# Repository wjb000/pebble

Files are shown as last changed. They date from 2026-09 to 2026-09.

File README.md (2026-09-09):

# Pebble — HouseHand v3

Draft wheeled house-chore bot. App pages:

- **Model:** [/pebble/model](https://wjb000.github.io/pebble/model)
- **Sim:** [/pebble/sim](https://wjb000.github.io/pebble/sim) — teleop, chore demo, **Train BC / Test AI**
- **BOM:** [/pebble/bom](https://wjb000.github.io/pebble/bom)
- **Docs:** [/pebble/docs](https://wjb000.github.io/pebble/docs) — print kit + assembly + AI

Twin: LeKiwi 3-wheel omni → torso → XLe shoulder deck → dual SO-101 + cam head.  
Print: `print/README.md` · Assembly: `docs/ASSEMBLY.md` · Train: `docs/TRAIN.md`

## Controls (sim)

W/S forward · A/D strafe · ←/→ yaw · Q/E arms · F pick · G demo · TAB mode · Space e-stop.  
**AI:** teleop to record → Train BC → Test AI (panel on `/sim`).

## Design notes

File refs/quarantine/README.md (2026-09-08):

# Quarantine

Assets here are **not** part of the Pebble digital twin or product BOM.

- `microduck/` — leftover Pollen Microduck MJCF/NOTICE from an earlier biped experiment.
  Pebble is HouseHand v3 (omni + telescope + SO-ARM100). Do not reload into `public/assets/`.

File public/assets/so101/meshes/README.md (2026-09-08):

# SO-101 URDF visual meshes

Copied from [TheRobotStudio/SO-ARM100](https://github.com/TheRobotStudio/SO-ARM100) `Simulation/SO101/assets/` (Apache-2.0).

These are the Onshape-exported parts referenced by `../so101_new_calib.urdf` (meters). Print the follower from `print/SO101/Individual/` instead of these sim meshes.

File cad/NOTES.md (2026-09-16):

# CAD notes

HouseHand printable structure is generated from one geometry contract:

| Constant | Value | Role |
|---|---:|---|
| `TORSO_OD` / wall | 180 / **6 mm** | Clears 4″ omni tops; thicker wall for dual-arm load |
| `TORSO_FLANGE_OD` | 190 mm | Bolts to layer2; **wheel wells** over forward omnis |
| Flange bolts | `(40,±80)`, `(±80,±40)` | **6× Ø3.4** — `(−40,±80)` sit in the wells |
| Wheel wells | print 90–144° / 214–271°, Z=0–36 | Forward 4″ omnis spin through flange + lower tube |
| Split ring | Z=155–165, r=88, 6× M3 | Bed-size halves clamp (plus 4 pins) |
| Deck → torso | r=88, 30°/90°/… | **6× M3** through plate into top rim |
| Pad centers | (−26, ±138) mm | SO-101 L/R; **4× Ø5** on SO-ARM100 4040 48×46.5 mm rectangle |
| Cable | Ø36 through deck | Into hollow torso |
| Neck boss / bolts | Ø72 / Ø36; r=28 4× M3 | Collar and **generated head** share this circle |
| Head | visor helmet, flange Ø82, 4× M3 r=28 | Forward visor + 32×32 UVC (4× M2, 28 mm) |
| Deck splice | 180×24×5, 8× M3 | L/R seam bar |

## Generate

```bash
python3 scripts/gen_structure_kit.py
python3 scripts/prep_print_stls.py   # foot origins, bed splits, registration pins
python3 scripts/verify_structure_kit.py
```

Writes identical STLs to:
- `public/assets/xlerobot/hardware/HouseHand_{torso,shoulder_deck,neck,head_mount,head_camera}.stl`
- `print/xlerobot/hardware/` (same files)
- aliases `torso_shell.stl` → torso (**do not print twice**)

OpenSCAD sources: `cad/torso_shell.scad`, `cad/shoulder_deck.scad` (reference; Python generator is authoritative).

## Twin loads

`src/components/ImportedRobots.tsx` — LeKiwi URDF + HouseHand torso/deck/neck/head + 2× SO-101 URDF.  
No `TORSO_XY_WIDEN`, no shelf-trim / Z-gap hacks. Torso sits on **layer2** top.

## Wheel / base fit

- Print kit motor mounts = URDF `drive_motor_mount-v11` (×3).
- Print kit hubs = URDF `omni_wheel_mount-v5` (×3); wheels + drive servos are bought.
- Hex standoffs between layer1 and layer2 are bought (LeKiwi BOM) — required, not printed.
- Flange OD must stay ≤190 mm. Two **wheel wells** (print ~120° / ~240°) cut the flange and the lower 36 mm of tube so the forward omnis that poke above layer2 can spin. Seat those wells over the two forward wheels (camera faces drive-forward).

## Not part of the kit

RÅSKOG cart, XLe fragments, perceptron base, Prusa Z — see `print/_archive/`.

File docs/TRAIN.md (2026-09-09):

# Train & test AI in the browser twin

The `/sim` page records teleop and trains a small **behavioral cloning** policy in-browser (no server).

## Loop

1. Open `/sim` → press **DRIVE**
2. **TAB** or Train panel → **Teleop**
3. Drive toward the beacon / box (W/A/S/D, arrows). Recording is on by default.
4. **Train BC** when you have ≥40 moving samples
5. **Test AI** — mode switches to `POLICY`; the linear net drives from the same observation vector
6. **Space** e-stop / reset pose (keeps trajectory). **Clear traj** / **Clear AI** wipe demos or weights.

## Observation → action

| Obs (normalized) | Action |
|---|---|
| ball dx/dy/bearing/range | `forward` |
| box dx/dy/range + held | `strafe` |
| v, omega, lift frac, arm shoulder | `yawRate` |

Fixed control rate **50 Hz** (`DT = 0.02`). Physics = planar holonomic mecanum (not MuJoCo).

## API

After Sim mounts:

```js
const t = window.__PEBBLE_TRAIN__
t.buffer.length
t.trainFromBuffer(40)
t.runPolicy()
t.downloadTrajectory()
t.downloadPolicy()
```

Weights persist in `localStorage` (`pebble-bc-policy-v1`).

## Honest limits

- BC copies your teleop style — garbage demos → garbage policy
- No vision / depth — state features only
- Arms/lift are observed but the action is base steering only (extend later)
- Stub **AUTO** (TAB) is still the simple beacon seeker when no policy is running

Print kit: `print/README.md`. Assembly: `docs/ASSEMBLY.md`.

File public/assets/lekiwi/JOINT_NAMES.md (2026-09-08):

# URDF joint names

The nine actuated joints use the same names as the LeKiwi motors in
[LeRobot](https://github.com/huggingface/lerobot/blob/main/src/lerobot/robots/lekiwi/lekiwi.py).
This makes joint-state and command dictionaries directly comparable between the
robot driver and the URDF.

| LeRobot/URDF name | Previous generated URDF name |
| --- | --- |
| `base_left_wheel` | `ST3215_Servo_Motor-v1_Revolute-64` |
| `base_back_wheel` | `ST3215_Servo_Motor-v1-2_Revolute-60` |
| `base_right_wheel` | `ST3215_Servo_Motor-v1-1_Revolute-62` |
| `arm_shoulder_pan` | `STS3215_03a-v1_Revolute-45` |
| `arm_shoulder_lift` | `STS3215_03a-v1-1_Revolute-49` |
| `arm_elbow_flex` | `STS3215_03a-v1-2_Revolute-51` |
| `arm_wrist_flex` | `STS3215_03a-v1-3_Revolute-53` |
| `arm_wrist_roll` | `STS3215_03a_Wrist_Roll-v1_Revolute-55` |
| `arm_gripper` | `STS3215_03a-v1-4_Revolute-57` |

Consumers that refer to joints by name must update from the generated names in
the right column to the stable names in the left column.

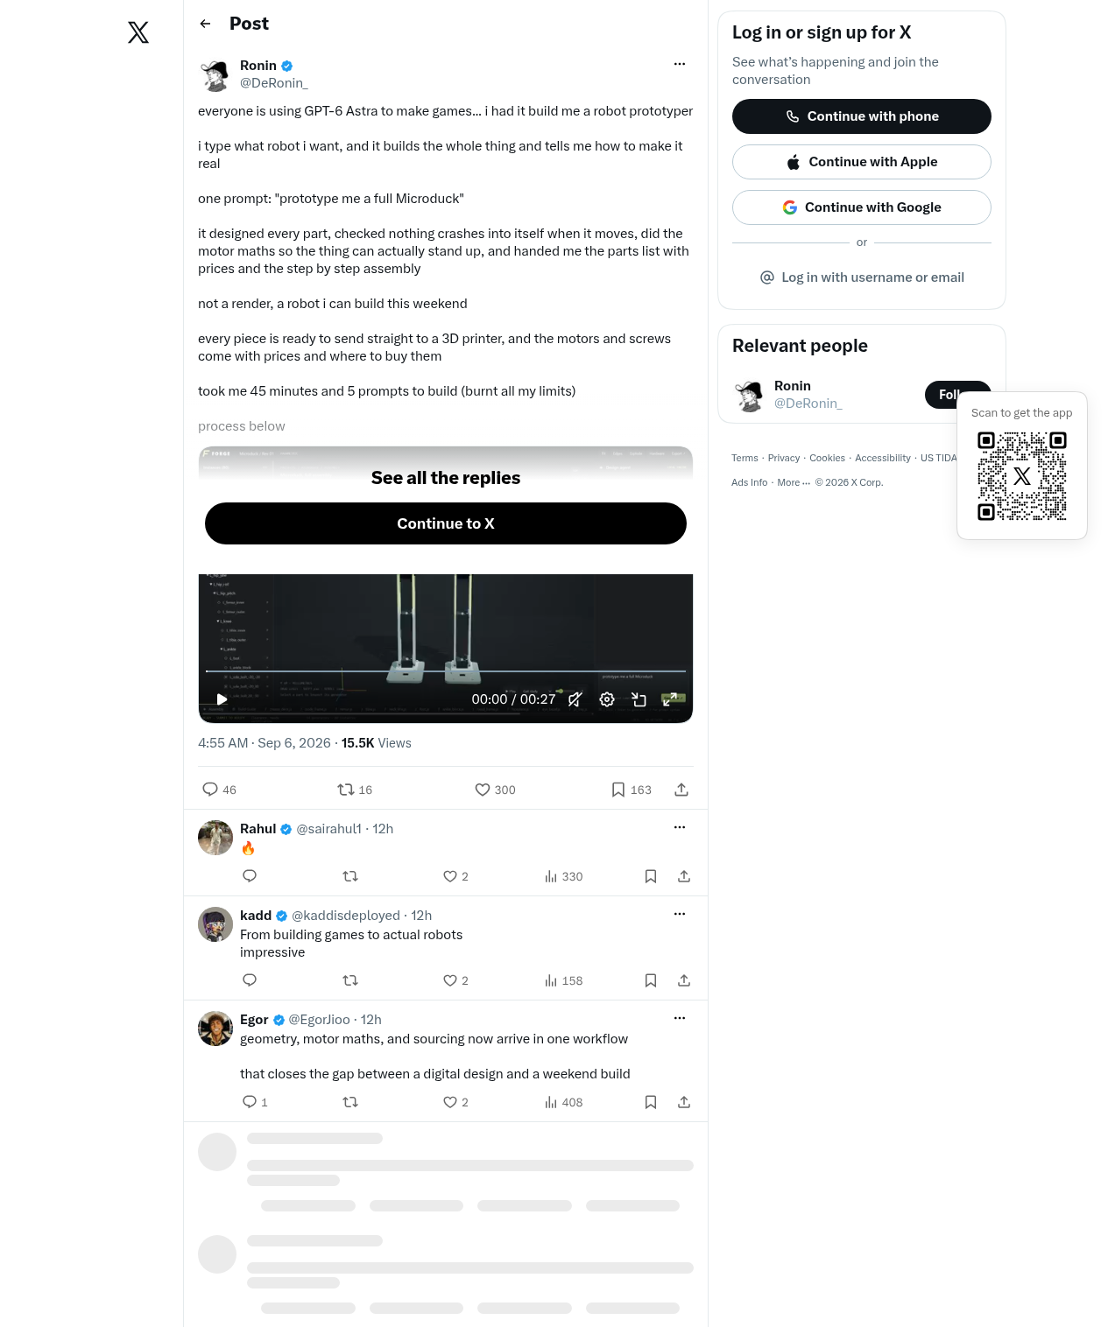
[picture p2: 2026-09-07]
refs/ronin-tweet.png

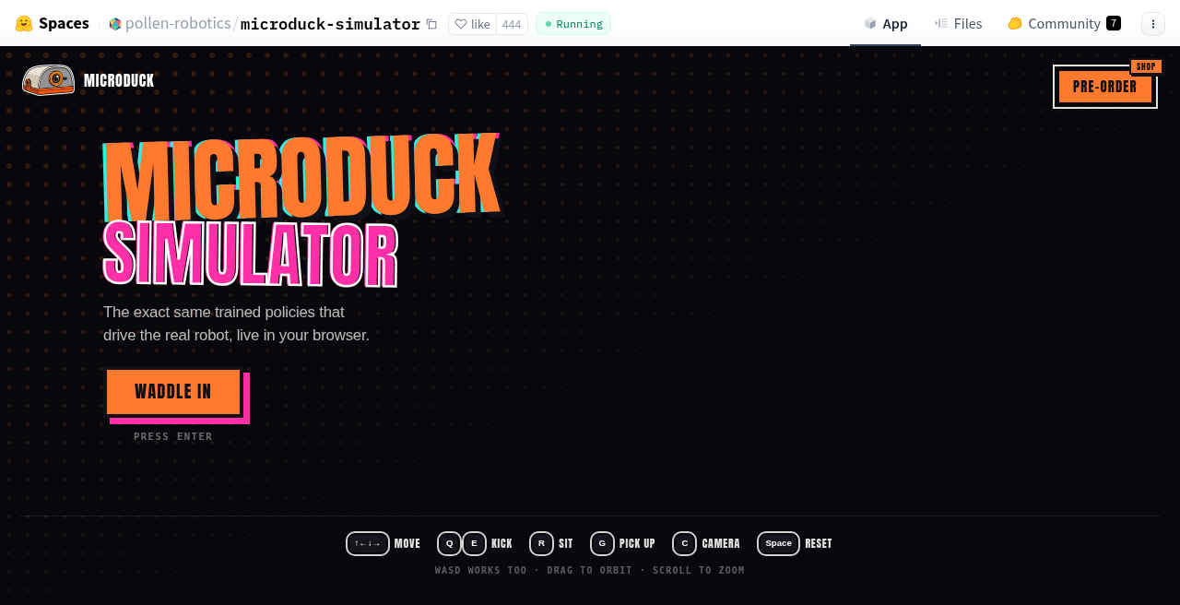
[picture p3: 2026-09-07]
refs/microduck-title.png

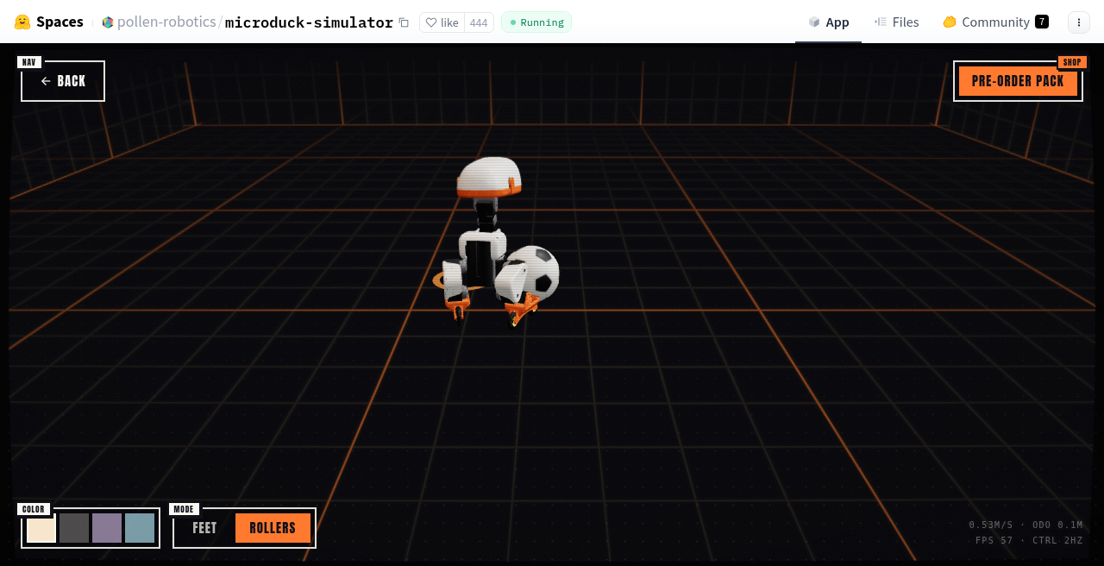
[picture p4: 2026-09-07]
refs/microduck-rollers.png

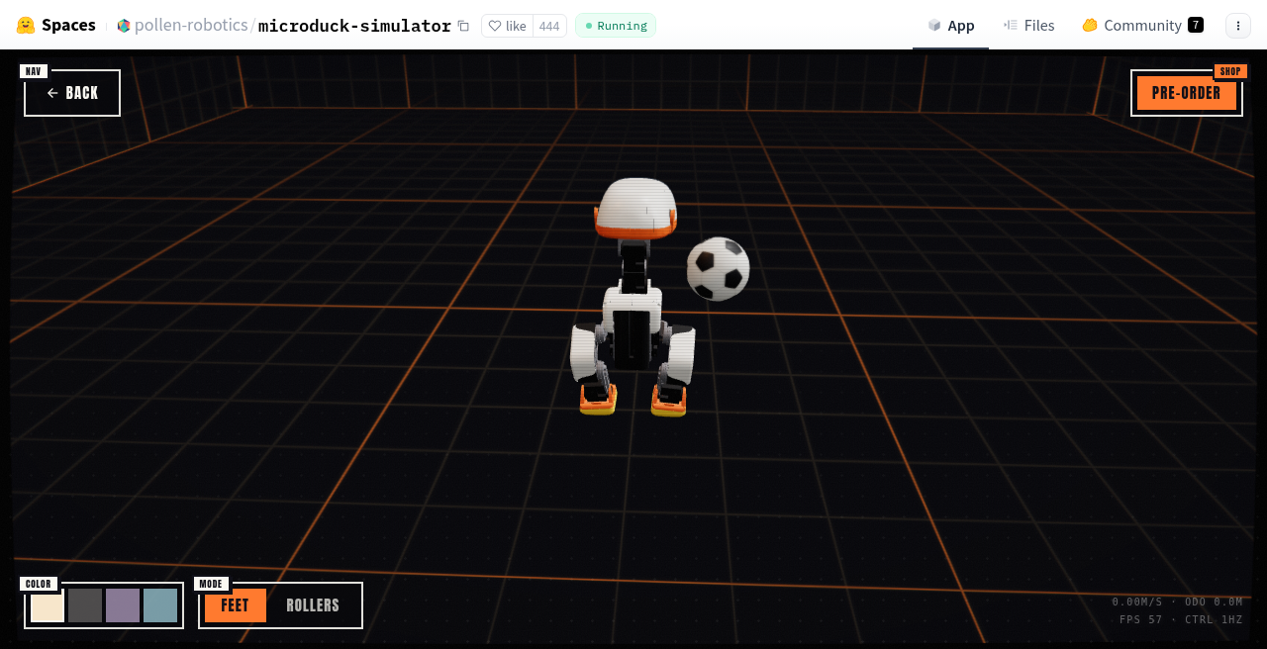
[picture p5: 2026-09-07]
refs/microduck-feet.png

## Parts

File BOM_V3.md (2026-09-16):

# HouseHand — Bill of Materials (v3.2)

**Product of record:** LeKiwi **3-omni** base + printed **HouseHand** torso/deck/neck/head + **2× SO-101** followers.  
**Rough total:** **~$500–750** DIY (print yourself). Street USD hobby prices, 2026 — verify before buy.

Print list: `print/README.md`. Assembly: `docs/ASSEMBLY.md`. Twin: `/model`.

---

## A. Arms (2× SO-101 follower)

| # | Part | Qty | ~$ | Notes |
|---|---|---:|---:|---|
| A1 | Feetech STS3215 (C001 / 7.4V or 12V match) | **12** | 168 | 6 per follower |
| A2 | Waveshare bus servo adapter | 2 | 22 | One bus per arm |
| A3 | 5V ≥5A (or 12V) rail for arms | 1–2 | 12–24 | Match motor voltage |
| A4 | USB-C data cables | 2 | 8 | Bus → host |
| A5 | PLA+/PETG filament (2× follower) | ~0.8 kg | 16 | `print/SO101/` |
| A6 | Wrist UVC cams (optional) | 0–2 | 0–30 | + `Wrist_camera_mount_SO101.stl` ×2 |
| | **Arms subtotal** | | **~$230–270** | |

Upstream: https://github.com/TheRobotStudio/SO-ARM100

---

## B. HouseHand structure (printed)

| # | Part | Qty | ~$ | Notes |
|---|---|---:|---:|---|
| B1 | `HouseHand_torso.stl` Ø180 / **6 mm wall** / flange Ø190 × 320 mm | 1 | filament | Seats on layer2; **wheel wells** over forward omnis; split ring if bed-limited |
| B2 | `HouseHand_shoulder_deck.stl` (+ splice if L/R) | 1 | filament | Pads (−26, ±138); Ø36 cable hole |
| B3 | `HouseHand_neck.stl` | 1 | filament | 4× M3 into deck boss |
| B4 | `HouseHand_head_mount.stl` visor helmet + `HouseHand_head_camera.stl` | 1 | filament | Head flange **prints** 4× M3 at r=28; visor takes 32×32 UVC + clamp plate |
| B5 | M3 + M4 hardware pack | 1 | 12–18 | Flange **6×M3**, rim 6×M3, split 6×M3, splice 8×M3, neck/head 8×M3, pads **8× M4×30** + wing nuts |
| | **Structure subtotal** | | **~$25–45** | filament + fasteners |

Generate: `python3 scripts/gen_structure_kit.py`

---

## C. LeKiwi omni base

| # | Part | Qty | ~$ | Notes |
|---|---|---:|---:|---|
| C1 | Printed plates + mounts (`print/lekiwi/`) | 1 set | filament | layer1, layer2, 3× drive mount v11, 3× hub, battery, Pi case, controller mount |
| C2 | **4″ omni wheels** (bought) | **3** | 35–50 | Not printed |
| C3 | **STS3215 drive servos** | **3** | 42–50 | Bridge: mount → hub → wheel |
| C4 | Waveshare bus (drive) | 1 | 11 | Or share a bus carefully |
| C5 | **Hex standoffs** McMaster-class **`94868A713`** (M3 ♀ threaded, ~50 mm stack height per URDF) | **6** | 8–15 | **Required** between layer1 ↔ layer2 |
| C6 | M3 screws for plates / mounts / standoffs | — | 8–12 | |
| | **Base subtotal** | | **~$110–160** | |

Upstream: https://github.com/SIGRobotics-UIUC/LeKiwi

---

## D. Power, compute, safety

| # | Part | Qty | ~$ | Notes |
|---|---|---:|---:|---|
| D1 | 12 V pack + BMS (centered in base bay) | 1 | 50–120 | Tip ballast |
| D2 | 5 V buck | 1–2 | 5–10 | Logic / hub / cams |
| D3 | Powered USB hub | 1 | 15 | Buses + cams |
| D4 | Laptop you own **or** Pi 5 | 0–1 | 0–80 | |
| D5 | USB gamepad | 1 | 20 | Teleop |
| D6 | Latching e-stop | 1 | 8–12 | Cuts drive + arms |
| D7 | Wire, XT60, fuses, switch | — | 15–25 | |
| D8 | Head UVC camera | 1 | 15–30 | On HouseHand head mount |
| | **Power/compute subtotal** | | **~$130–280** | |

---

## Cost rollup

| Block | Low | High |
|---|---:|---:|
| A Arms | 230 | 270 |
| B Structure (print) | 25 | 45 |
| C Omni base | 110 | 160 |
| D Power/compute | 130 | 220 |
| **Total** | **~$495** | **~$695** |

---

## Buy order
1. **C2+C3+C5** — omni wheels, 3× drive STS3215, **6× standoffs** (base cannot assemble without these)
2. **A1** — first 6× STS + one follower bring-up
3. Rest of **A** — second arm
4. Print **C1 + B** while hardware ships
5. **D** — pack, e-stop, compute, head cam

## Do not buy
RÅSKOG cart · 4× mecanum deck (this twin is **3-omni**) · ODrive/SteadyWin · Amazing Hand · nested telescoping column kit · exposed-rail-only lift · leader SO-101 (unless you want teleop leader)

## Sketch
- Twin stack on `/model` matches `print/` STLs
- This BOM: `BOM_V3.md` · UI: `/bom`

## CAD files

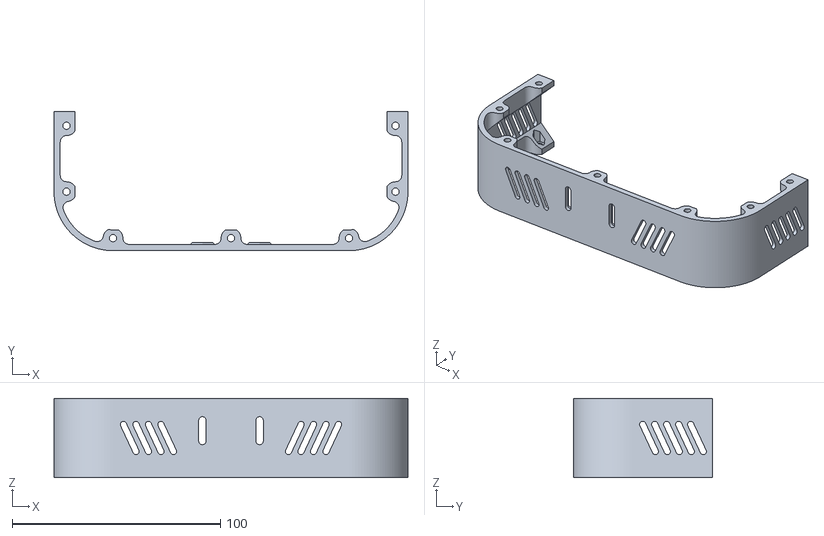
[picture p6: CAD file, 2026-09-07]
print/base/back_lower_wall.stl
170.0 x 66.9 x 38.0

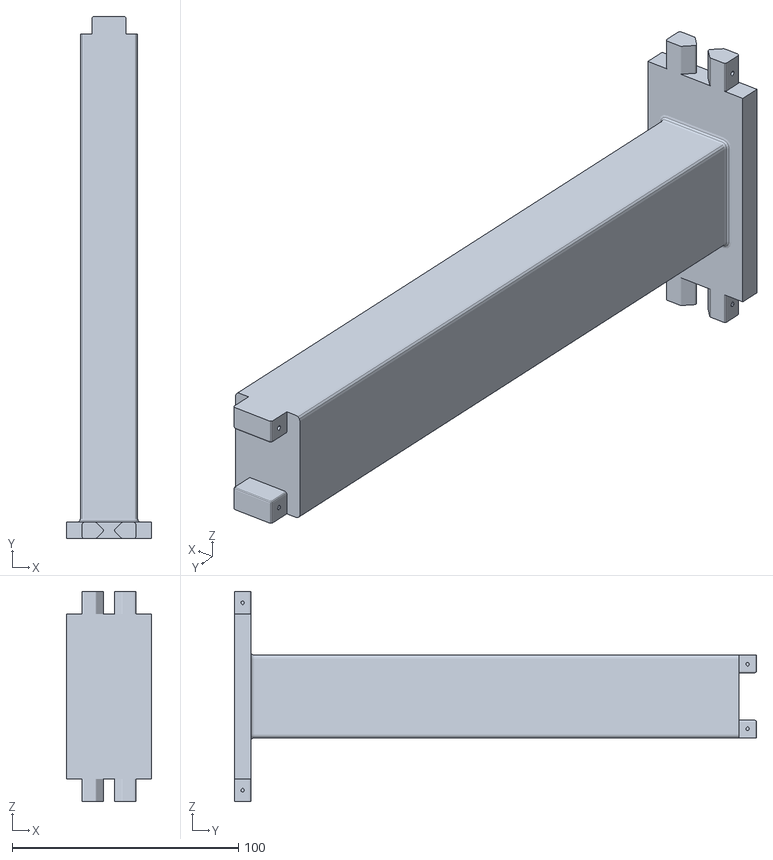
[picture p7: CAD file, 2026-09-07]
print/head/cam_mount_bottom.stl
37.4 x 230.9 x 93.0

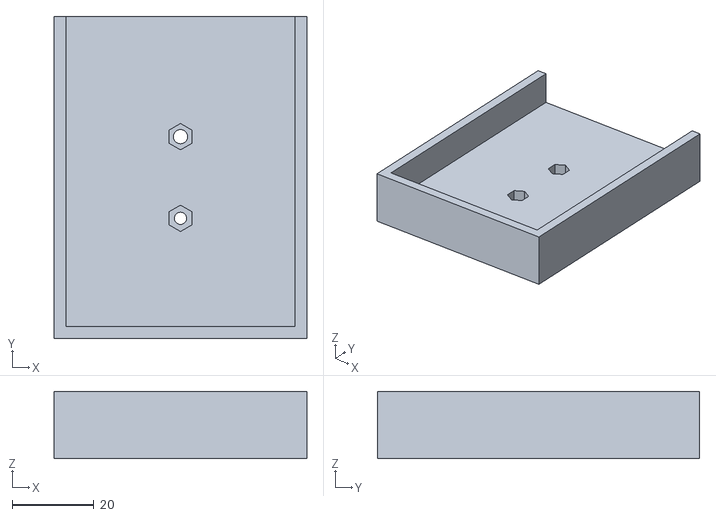
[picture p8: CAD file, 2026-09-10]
print/lekiwi/battery_mount.stl
62.0 x 79.0 x 16.5

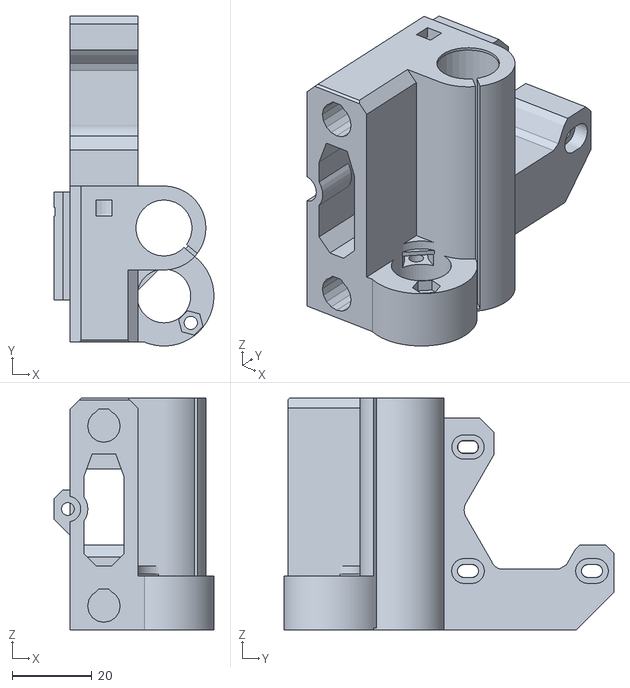
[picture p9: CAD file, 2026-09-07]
print/lift/carriage_x-end-motor.stl
40.0 x 82.5 x 58.0

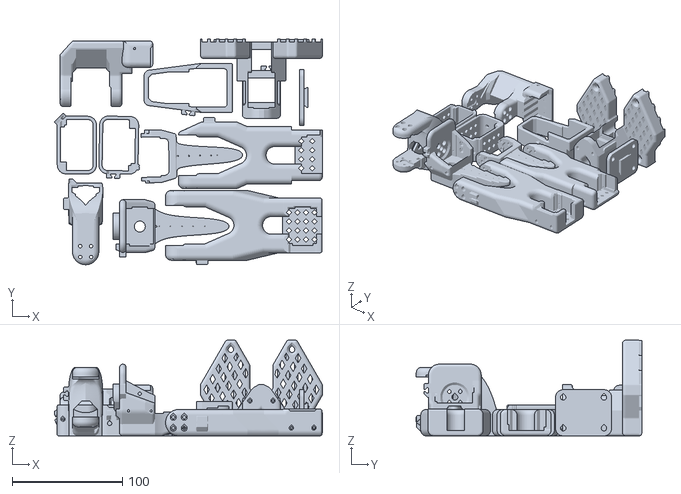
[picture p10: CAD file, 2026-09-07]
print/SO101/Follower/Prusa_Follower_SO101.stl
243.4 x 204.9 x 87.0

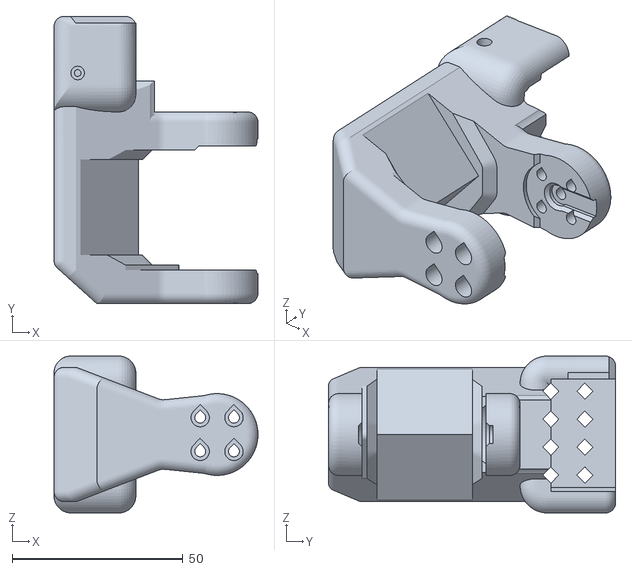
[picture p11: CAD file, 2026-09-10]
print/SO101/Individual/Rotation_Pitch_SO101.stl
59.8 x 84.2 x 46.0

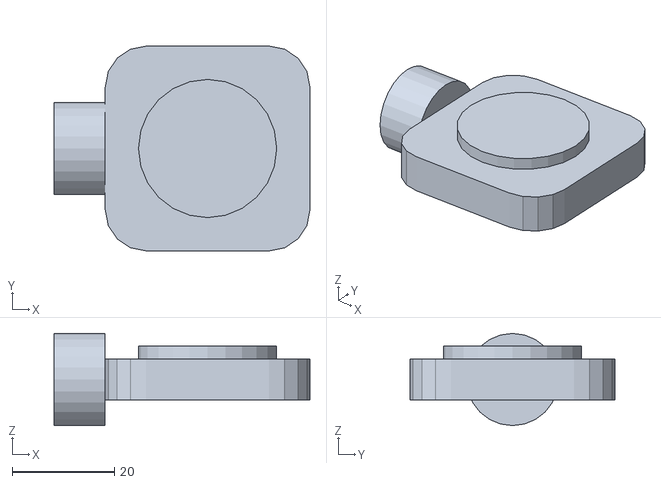
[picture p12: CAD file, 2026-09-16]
print/xlerobot/hardware/HouseHand_head_camera.stl
50.0 x 40.0 x 18.0

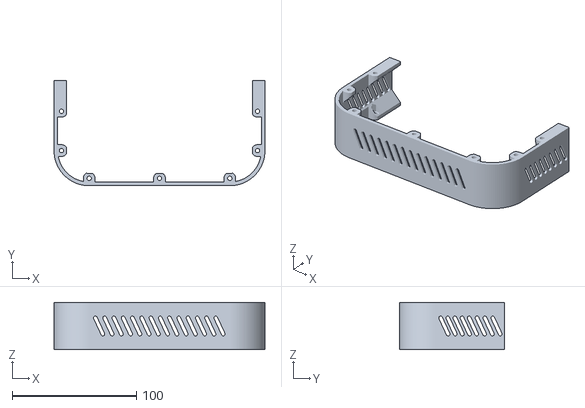
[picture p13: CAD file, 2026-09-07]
public/assets/base/back_upper_wall.stl
170.0 x 85.0 x 38.0

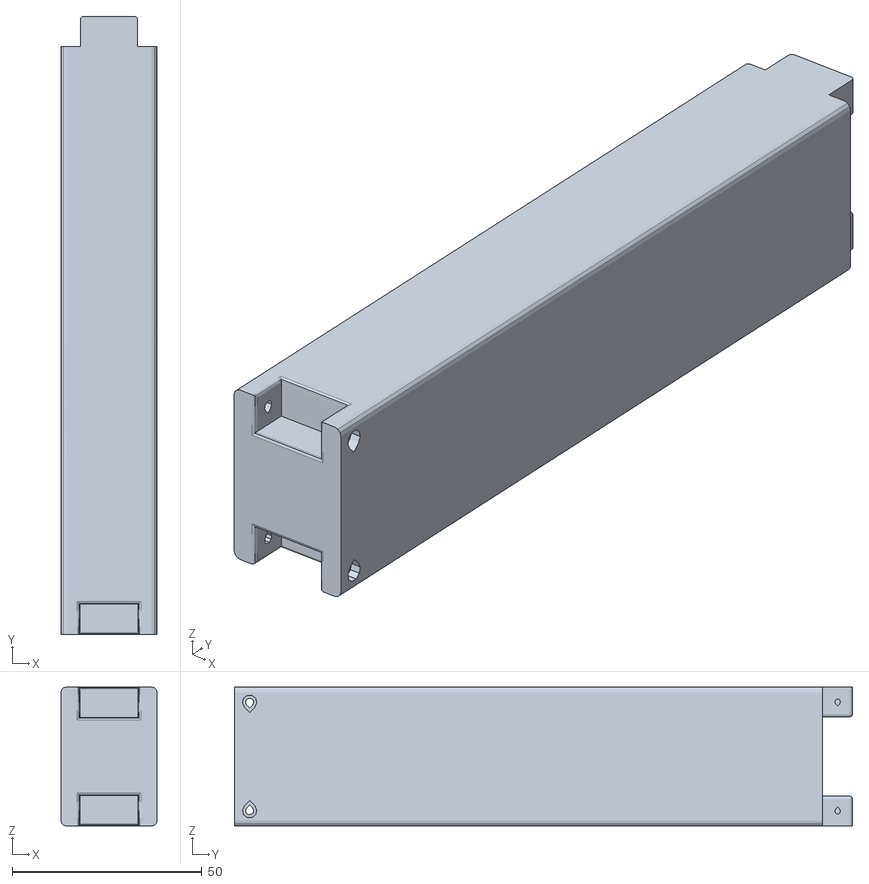
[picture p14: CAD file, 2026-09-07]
public/assets/head/cam_mount_middle.stl
25.4 x 162.9 x 36.6

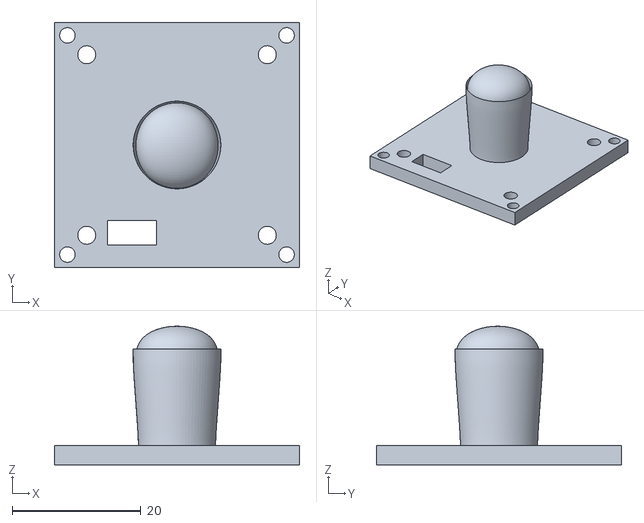
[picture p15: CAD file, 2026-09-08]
public/assets/lekiwi/meshes/Camera-Model-v3.stl
38.0 x 38.0 x 21.5

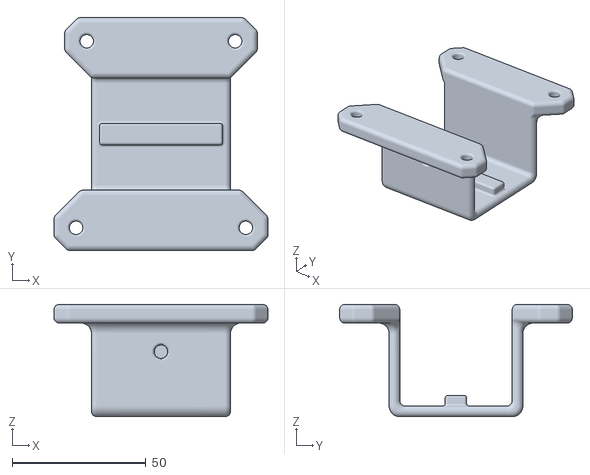
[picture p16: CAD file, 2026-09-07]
public/assets/lift/4040_base_mount.stl
80.0 x 87.0 x 42.0

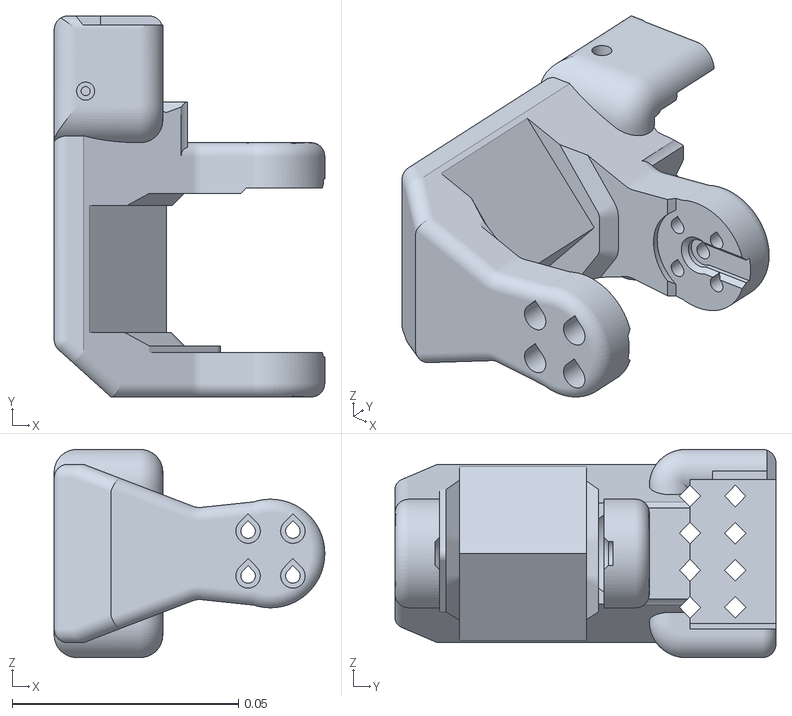
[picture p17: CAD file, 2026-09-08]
public/assets/so101/meshes/rotation_pitch_so101_v1.stl
0.0598 x 0.0842 x 0.046

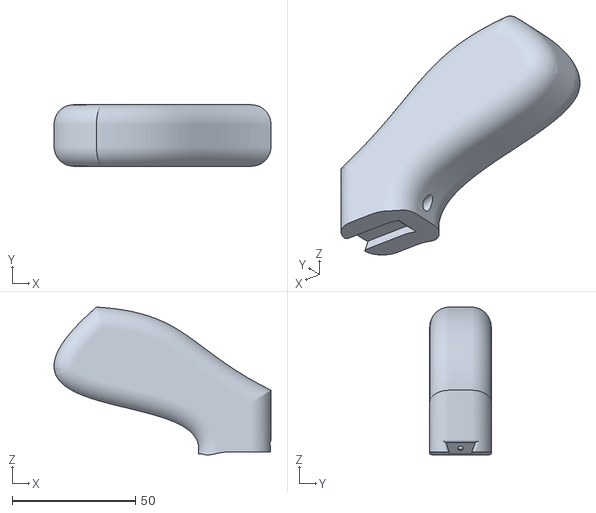
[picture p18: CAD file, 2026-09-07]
public/assets/so101/print/Handle_SO101.stl
88.1 x 25.0 x 60.1

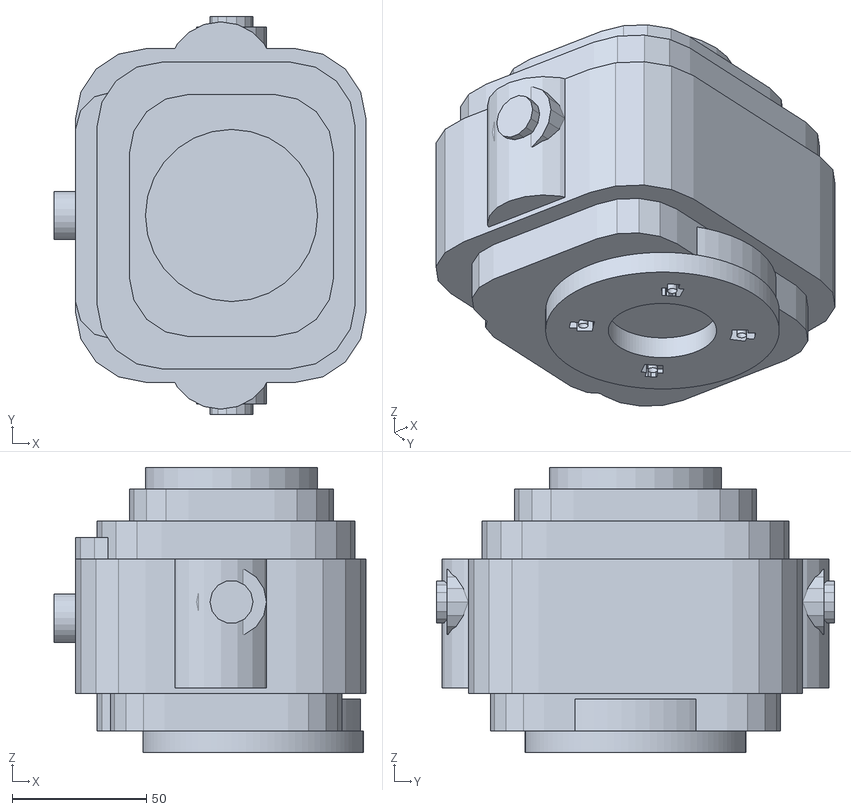
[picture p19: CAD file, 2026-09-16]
public/assets/xlerobot/hardware/HouseHand_head_mount.stl
116.0 x 148.0 x 106.0

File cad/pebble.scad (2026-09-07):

// Pebble CAD twin — chore-class body + 2× SO-101 arms
// MUST MATCH src/robot/dims.ts (hardcoded constants below).
// Units: millimeters. Open in OpenSCAD: File → Open → F5 preview / F6 render.
// NOT an official Pollen / legacy-ref product — public specs only.

// ===== must match dims.ts =====
XL330_L = 20.0;
XL330_W = 34.0;
XL330_H = 26.0;

STS3215_L = 45.2;
STS3215_W = 24.7;
STS3215_H = 35.0;

FOOT_L = 55;
FOOT_W = 32;
FOOT_H = 12;

SHIN_LEN = 48;
THIGH_LEN = 42;

PELVIS_W = 72;
PELVIS_H = 20;
PELVIS_D = 48;

TORSO_W = 100;
TORSO_H = 68;
TORSO_D = 78;

NECK_LEN = 22;

HEAD_W = 48;
HEAD_H = 38;
HEAD_D = 52;

BEAK_L = 28;
BEAK_W = 16;
BEAK_H = 10;

CAMERA_W = 12;
CAMERA_H = 12;
CAMERA_D = 8;

LINK_R = 6;
HORN_THICKNESS = 2.5;

SO101_UPPER = 112.6;
SO101_FORE = 134.9;
SO101_WRIST = 61.1;
SO101_GRIP = 80;
SO101_BASE_Z = 62.4;

SHOULDER_SPAN = 140;
HIP_LATERAL = 30;

PI_W = 65;
PI_H = 30;
PI_D = 12;

BAT_W = 40;
BAT_H = 18;
BAT_D = 30;

JOINT_YAW_TO_ROLL = 12;
JOINT_ROLL_TO_PITCH = 16;

STANDING_HEIGHT =
  FOOT_H + SHIN_LEN + THIGH_LEN + PELVIS_H + TORSO_H + NECK_LEN + HEAD_H;
// expect 250
HIP_HEIGHT = FOOT_H + SHIN_LEN + THIGH_LEN; // 102

$fn = 24;

module servo_xl330() {
  color([0.2, 0.22, 0.26])
    cube([XL330_L, XL330_H, XL330_W], center = true);
  color([0.95, 0.45, 0.1])
    translate([XL330_L * 0.35, 0, 0])
      rotate([0, 90, 0])
        cylinder(h = HORN_THICKNESS, r = 2.5, center = true);
}

module servo_sts3215() {
  color([0.12, 0.16, 0.22])
    cube([STS3215_L, STS3215_H, STS3215_W], center = true);
  color([0.95, 0.45, 0.1])
    translate([STS3215_L * 0.35, 0, 0])
      rotate([0, 90, 0])
        cylinder(h = 3, r = 4, center = true);
}

module tube_link(len, r = LINK_R) {
  color([0.6, 0.65, 0.72])
    translate([0, -len / 2, 0])
      cylinder(h = len, r = r, center = true);
}

module foot() {
  color([0.18, 0.2, 0.24])
    translate([0, -FOOT_H / 2, FOOT_L * 0.15])
      cube([FOOT_W, FOOT_H, FOOT_L], center = true);
}

module leg(side = 1) {
  translate([side * HIP_LATERAL, 0, 0]) {
    rotate([0, 0, 90]) servo_xl330(); // hip_yaw
    translate([0, -JOINT_YAW_TO_ROLL, 0]) {
      servo_xl330(); // hip_roll
      translate([0, -JOINT_ROLL_TO_PITCH, 0]) {
        rotate([90, 0, 0]) servo_xl330(); // hip_pitch
        tube_link(THIGH_LEN, LINK_R * 0.85);
        translate([0, -THIGH_LEN, 0]) {
          rotate([90, 0, 0]) servo_xl330(); // knee
          tube_link(SHIN_LEN, LINK_R * 0.8);
          translate([0, -SHIN_LEN, 0]) {
            rotate([90, 0, 0]) servo_xl330(); // ankle
            foot();
          }
        }
      }
    }
  }
}

module duck_head() {
  rotate([90, 0, 0]) servo_xl330(); // neck_pitch
  color([0.2, 0.22, 0.26])
    translate([0, NECK_LEN * 0.4, 0])
      cylinder(h = NECK_LEN * 0.75, r1 = 10, r2 = 8, center = true);
  translate([0, NECK_LEN * 0.85, 0]) {
    rotate([90, 0, 0]) servo_xl330(); // head_pitch
    translate([0, 10, 0]) {
      rotate([0, 0, 90]) servo_xl330(); // head_yaw
      translate([0, 10, 0]) {
        servo_xl330(); // head_roll
        color([0.6, 0.64, 0.7])
          translate([0, HEAD_H * 0.25, 0])
            cube([HEAD_W, HEAD_H, HEAD_D], center = true);
        // beak
        rotate([90, 0, 0]) servo_xl330();
        color([0.95, 0.45, 0.1])
          translate([0, -2, BEAK_L * 0.45])
            cube([BEAK_W, BEAK_H, BEAK_L], center = true);
        color([0.1, 0.1, 0.12])
          translate([0, HEAD_H * 0.55 + CAMERA_H / 2, 4])
            cube([CAMERA_W, CAMERA_H, CAMERA_D], center = true);
      }
    }
  }
}

module so101_arm(side = 1) {
  translate([side * SHOULDER_SPAN / 2, TORSO_H * 0.28, 8]) {
    // mount plate
    color([0.18, 0.2, 0.24])
      translate([-side * 8, 0, 0])
        cube([18, 28, 14], center = true);
    rotate([0, 0, 90]) servo_sts3215(); // shoulder_pan
    color([0.2, 0.22, 0.26])
      translate([0, SO101_BASE_Z * 0.35, 0])
        cylinder(h = SO101_BASE_Z * 0.7, r1 = 20, r2 = 18, center = true);
    translate([0, SO101_BASE_Z * 0.75, 0]) {
      servo_sts3215(); // shoulder_lift
      rotate([30, 0, side * 5]) {
        tube_link(SO101_UPPER, 10);
        translate([0, -SO101_UPPER, 0]) {
          rotate([90, 0, 0]) servo_sts3215(); // elbow
          rotate([-65, 0, 0]) {
            tube_link(SO101_FORE, 9);
            translate([0, -SO101_FORE, 0]) {
              rotate([90, 0, 0]) servo_sts3215(); // wrist_flex
              translate([0, -SO101_WRIST * 0.35, 0]) {
                servo_sts3215(); // wrist_roll
                translate([0, -SO101_WRIST * 0.7, 0]) {
                  rotate([0, 0, 90]) servo_sts3215(); // gripper
                  color([0.8, 0.82, 0.86]) {
                    translate([-12, -SO101_GRIP * 0.35, 0])
                      cube([8, SO101_GRIP * 0.7, 14], center = true);
                    translate([12, -SO101_GRIP * 0.35, 0])
                      cube([8, SO101_GRIP * 0.7, 14], center = true);
                  }
                }
              }
            }
          }
        }
      }
    }
  }
}

module pebble() {
  translate([0, HIP_HEIGHT, 0]) {
    color([0.18, 0.2, 0.24])
      cube([PELVIS_W, PELVIS_H, PELVIS_D], center = true);
    leg(+1);
    leg(-1);
    translate([0, PELVIS_H / 2 + TORSO_H / 2, 0]) {
      color([0.6, 0.64, 0.7])
        cube([TORSO_W, TORSO_H, TORSO_D], center = true);
      color([0.15, 0.45, 0.3])
        translate([-12, 8, -TORSO_D * 0.28])
          cube([PI_W, PI_H, PI_D], center = true);
      color([0.2, 0.22, 0.26])
        translate([22, -12, -TORSO_D * 0.28])
          cube([BAT_W, BAT_H, BAT_D], center = true);
      translate([0, TORSO_H / 2 + NECK_LEN * 0.1, 0])
        duck_head();
      so101_arm(+1);
      so101_arm(-1);
    }
  }
  color([0.95, 0.45, 0.1]) {
    translate([120, STANDING_HEIGHT / 2, 0])
      cube([3, STANDING_HEIGHT, 3], center = true);
    translate([120, 0, 0]) cube([24, 2, 24], center = true);
    translate([120, STANDING_HEIGHT, 0]) cube([24, 2, 24], center = true);
  }
}

echo(str("STANDING_HEIGHT_MM = ", STANDING_HEIGHT, " (must be 250)"));
echo(str("HIP_HEIGHT_MM = ", HIP_HEIGHT));
echo("must match dims.ts — legacy-ref body + SO-101 arms");

pebble();

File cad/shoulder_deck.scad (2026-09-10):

// HouseHand shoulder deck — dual SO-101 pads + neck boss.
// Units: mm. Flat on bed. Prefer: python3 scripts/gen_structure_kit.py

plate_x = 200;
plate_y = 380;
plate_z = 12;
corner_r = 28;

pad_x = -26;
pad_half_y = 138;
pad_r = 52;
pad_z = 6;
// 4× Ø5 on SO-ARM100 4040 pattern (see scripts/gen_structure_kit.py)

torso_od = 180;
ring_clear = 0.6;
ring_z = 4;

neck_boss_r = 36;
neck_boss_z = 14;
neck_hole_r = 18;

module rounded_plate(wx, wy, hz, r) {
  hull() for (sx = [-1, 1], sy = [-1, 1])
    translate([sx * (wx/2 - r), sy * (wy/2 - r), 0])
      cylinder(h = hz, r = r, $fn = 48);
}

difference() {
  union() {
    rounded_plate(plate_x, plate_y, plate_z, corner_r);
    // registration ring (underside)
    translate([0, 0, -ring_z])
      difference() {
        cylinder(h = ring_z, r = torso_od/2 + ring_clear + 3, $fn = 96);
        translate([0, 0, -0.1])
          cylinder(h = ring_z + 0.2, r = torso_od/2 + ring_clear, $fn = 96);
      }
    // SO-101 pads
    for (sy = [-1, 1]) {
      translate([pad_x, sy * pad_half_y, plate_z])
        cylinder(h = pad_z, r = pad_r, $fn = 64);
    }
    // neck boss
    translate([0, 0, plate_z])
      difference() {
        cylinder(h = neck_boss_z, r = neck_boss_r, $fn = 64);
        translate([0, 0, -0.1])
          cylinder(h = neck_boss_z + 0.2, r = neck_hole_r, $fn = 48);
      }
  }
}

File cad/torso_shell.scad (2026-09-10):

// HouseHand torso — mates LeKiwi layer2 (bottom) + shoulder deck (top).
// Units: mm. Export STL → print/xlerobot/hardware/HouseHand_torso.stl
// Prefer: python3 scripts/gen_structure_kit.py  (same geometry — authoritative)
//
// Two forward 4″ omnis poke above layer2. Wheel wells (print 90–144° /
// 214–271°) cut the flange + lower 36 mm of tube so the tires can spin.
// Seat those wells over the forward omnis (camera faces drive-forward).
// Flange bolts: 6× M3 on the layer2 20 mm grid. (−40, ±80) sit in the wells.

OD = 180;
WALL = 6;
H = 320;
FLANGE_OD = 190;
FLANGE_Z = 10;
RIM_Z = 6;
WHEEL_WELL_Z = 36;
HOLE_R = 1.7; // M3 clearance
BOLTS = [
  [40, 80], [40, -80],
  [80, 40], [80, -40], [-80, 40], [-80, -40]
];
WELLS = [[90, 144], [214, 271]];
$fn = 72;

module well_cut(a0, a1, h) {
  rotate([0, 0, a0])
    rotate_extrude(angle = a1 - a0)
      square([FLANGE_OD / 2 + 2, h]);
}

difference() {
  union() {
    cylinder(h = FLANGE_Z, d = FLANGE_OD);
    translate([0, 0, FLANGE_Z])
      cylinder(h = H - FLANGE_Z - RIM_Z, d = OD);
    translate([0, 0, H - RIM_Z])
      cylinder(h = RIM_Z, d = OD + 4);
  }
  translate([0, 0, -1])
    cylinder(h = H + 2, d = OD - 2 * WALL);
  for (b = BOLTS)
    translate([b[0], b[1], -1])
      cylinder(h = FLANGE_Z + 2, r = HOLE_R, $fn = 24);
  for (w = WELLS)
    translate([0, 0, -1])
      well_cut(w[0], w[1], WHEEL_WELL_Z + 2);
}

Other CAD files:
public/assets/xlerobot/xlerobot/meshes/xlerobot/assets/Lower_Arm_Motor.stl
print/base/wheel_frame.stl
print/lekiwi/base_plate_layer2.stl
print/SO101/Individual/Base_SO101.stl
print/SO101/Individual/Base_motor_holder_SO101.stl
print/SO101/Individual/Motor_holder_SO101_Base.stl
print/SO101/Individual/Motor_holder_SO101_Wrist.stl
print/SO101/Individual/Moving_Jaw_SO101.stl
print/SO101/Individual/Under_arm_SO101.stl
print/SO101/Individual/Upper_arm_SO101.stl
print/SO101/Individual/Wrist_Roll_Follower_SO101.stl
print/SO101/Individual/Wrist_Roll_Pitch_SO101.stl
print/SO101/Individual/Wrist_camera_mount_SO101.stl
print/_archive/SO101/leader/Trigger_SO101.stl
print/_archive/SO101/leader/Wrist_Roll_SO101.stl
print/_archive/base/front_lower_wall.stl
print/_archive/base/front_upper_wall.stl
print/_archive/base/lower_plate.stl
print/_archive/base/middle_plate_raspberry.stl
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

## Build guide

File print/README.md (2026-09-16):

# HouseHand / Pebble — print kit (one robot)

Send **only** these folders to the slicer. The twin on `/model` loads the **same** STLs.

**Stack:** LeKiwi 3-omni base → **HouseHand torso Ø180 / flange Ø190** → **shoulder deck** → **2× SO-101** → **neck** → **head + cam**

Do **not** print `print/_archive/` (legacy, leader-only, optional extras).

---

## Bed size (read this first)

| Part | Full size | Fits typical bed? | Split STLs (≤220 mm) |
|---|---|---|---|
| Torso | **190×190×320** | Needs **Z ≥ 320** | `HouseHand_torso_bottom.stl` + `_top.stl` (split bolt-ring + **4 registration pins**) — **6× M3×16** at seam |
| Shoulder deck | **200×380×30** | Needs **one axis ≥ 380** | `_L` + `_R` + `HouseHand_deck_splice.stl` (**8× M3**) — pins on cut |
| SO-101 Prusa plate | **~243×205×87** | Needs **≥250 mm** bed | Else print `SO101/Individual/` ×2 |
| Everything else | ≤200 mm | Fine on 220³ | — |

All kit STLs under `print/` are **footed to bed origin** (min-Z = 0). Hardware XY is centered; LeKiwi / SO-101 keep assembly XY. Regenerate with `python3 scripts/prep_print_stls.py`.

### Torso → layer2 bolts (critical)

Flange has **6× Ø3.4 through-holes** on the LeKiwi layer2 **20 mm grid**:
`(40, ±80)` and `(±80, ±40)` mm. **Two forward-omni wells** (print ~90–144° and ~214–271°) cut the flange + lower 36 mm of tube so the 4″ wheels can spin — `(−40, ±80)` would sit in those arches and are omitted. Seat the wells over the two forward omnis (camera faces drive-forward). Use M3 through the remaining holes — not freehand drilling.

### Fastener map (printed structure)

| Joint | Hardware | Pattern |
|---|---|---|
| Torso flange → layer2 | **6× M3** | `(40,±80)`, `(±80,±40)` — wells over forward omnis |
| Torso split (if using halves) | **6× M3×16** + pins | r=88 mm, 0°/60°/… |
| Deck → torso rim | **6× M3** | r=88 mm, 30°/90°/… |
| Deck L/R splice | **8× M3** + `HouseHand_deck_splice.stl` | y=±8, x=±20/±60 |
| SO-101 pads | **4× M4 per arm** (Ø5) | 48×46.5 mm rectangle (SO-ARM100 4040 pattern) through pad+plate |
| Neck → deck boss | **4× M3** | r=28 mm @ 45° |
| Head → neck flange | **4× M3** | **printed** in `HouseHand_head_mount.stl` — same r=28 |
| Head cam module | **4× M2** | 28 mm square in the visor (32×32 UVC) + `HouseHand_head_camera.stl` clamp |
| Cable | — | Ø36 through deck + hollow torso |

---

## Master checklist

| # | Module | Path | Qty | Notes |
|---|---|---|----:|---|
| **1** | Omni base | `print/lekiwi/` | 1 set | Plates, 3× `drive_motor_mount`, 3× `servo_wheel_hub`, battery, Pi case, controller mount |
| **2** | Torso | `HouseHand_torso.stl` **or** `_bottom`+`_top` | 1 | Ø180 / **6 mm wall** / flange Ø190 → layer2, **wheel wells** over the two forward omnis. Skip `torso_shell.stl`. |
| **3** | Shoulder deck | `HouseHand_shoulder_deck.stl` **or** `_L`+`_R` + `_deck_splice` | 1 | Pads (−26, ±138); Ø36 cable hole |
| **4** | Arms | `print/SO101/` | **2×** | Follower set twice — see folder README |
| **5** | Wrist cams (opt.) | `SO101/Individual/Wrist_camera_mount_SO101.stl` | 0–2 | |
| **6** | Neck | `HouseHand_neck.stl` | 1 | Deck center boss |
| **7** | Head | `HouseHand_head_mount.stl` + `HouseHand_head_camera.stl` | 1 | Visor helmet **bolts** to neck (4× M3 at r=28). Clamp plate sandwiches a bought 32×32 UVC |

Structure files live under `print/xlerobot/hardware/`.

### Must **buy** (not printed)

| Item | Qty | Why |
|---|----:|-----|
| 4″ omni wheels | **3** | Drive |
| STS3215 drive servos | **3** | Mount → hub bridge |
| Hex standoffs M3 (`94868A713` class) | **6** | Layer1 ↔ layer2 |
| STS3215 arm servos | **12** | 2× SO-101 |
| 12 V pack, e-stop, Pi/laptop, head cam | 1 | Power / safety / compute |

Full buy list: `BOM_V3.md` · Assembly: `docs/ASSEMBLY.md`

### Regenerate structure STLs

```bash
python3 scripts/gen_structure_kit.py
python3 scripts/prep_print_stls.py   # foot origins + bed splits + registration pins
python3 scripts/verify_structure_kit.py
```

---

## Filament (rough)

| Block | PLA+/PETG |
|---|---|
| LeKiwi base | 400–600 g |
| Torso + deck + neck + head | 700–1100 g |
| 2× SO-101 follower | 600–800 g |
| **Total** | **~1.8–2.5 kg** |

Archive / optional: `print/_archive/README.md` · Sim AI: `/sim`

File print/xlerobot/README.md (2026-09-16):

# HouseHand structure printables

```bash
python3 scripts/gen_structure_kit.py
python3 scripts/prep_print_stls.py   # required: bed origin + splits
```

## Print these

| File | Qty | Size | Notes |
|---|----:|---|---|
| `hardware/HouseHand_torso.stl` | 1 | 190×190×**320** | Needs tall Z **or** use splits below |
| `hardware/HouseHand_torso_bottom.stl` | 1 | 190×190×**160** | Glue/bolt to top at mid seam |
| `hardware/HouseHand_torso_top.stl` | 1 | 184×184×**160** | |
| `hardware/HouseHand_shoulder_deck.stl` | 1 | 200×**380**×30 | Needs ≥380 mm axis **or** use L/R |
| `hardware/HouseHand_shoulder_deck_L.stl` | 1 | 200×190×30 | Bolt to R across center |
| `hardware/HouseHand_shoulder_deck_R.stl` | 1 | 200×190×30 | |
| `hardware/HouseHand_neck.stl` | 1 | 82×82×120 | 4× M3 at r=28 both ends |
| `hardware/HouseHand_head_mount.stl` | 1 | **116×148×106** | Visor helmet, neck bolt circle, 32×32 UVC visor |
| `hardware/HouseHand_head_camera.stl` | 1 | ~40×40×10 | Clamp plate sandwiches the UVC (4× M2) |

`torso_shell.stl` aliases `HouseHand_torso.stl`.

**Small beds (≤220 mm):** print `_bottom`+`_top` and `_L`+`_R` instead of the full torso/deck.

## Do not print from archive

See `print/_archive/` for old XLe decks / RÅSKOG armbase / optional overhead cam.

Base: `print/lekiwi/` · Arms: **2×** `print/SO101/` · Master: `print/README.md`

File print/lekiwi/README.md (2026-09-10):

# LeKiwi print STLs — omni base

Upstream [SIGRobotics-UIUC/LeKiwi](https://github.com/SIGRobotics-UIUC/LeKiwi) (Apache-2.0).

Print these, then buy **3× 4″ omni wheels**, **3× STS3215** drive servos, and **6× M3 hex standoffs** (`94868A713` class).  
**Do not** print the onboard LeKiwi arm — HouseHand uses **2× SO-101** on the shoulder deck.

| STL | Qty | Notes |
|-----|----:|---|
| `base_plate_layer1.stl` | 1 | Bottom plate (URDF `base_plate_layer1-v5`) |
| `base_plate_layer2.stl` | 1 | Top plate — torso bolts at `(±40,±80)` / `(±80,±40)` on the 20 mm grid |
| `drive_motor_mount.stl` | 3 | URDF `drive_motor_mount-v11` |
| `servo_wheel_hub.stl` | 3 | URDF `omni_wheel_mount-v5` — hub only; wheel bought |
| `servo_controller_mount.stl` | 1 | |
| `battery_mount.stl` (or `_eu`) | 1 | |
| `pi_case_top.stl` + `pi_case_bottom.stl` | 1 | |
| `base_camera_mount.stl` | 0–1 | Optional (head cam is on the neck) |

## Clearance / assembly

- Motors + hubs on **layer1**; hubs clear **layer2** underside ~4–5 mm.
- **6× hex standoffs** between layer1 ↔ layer2 — required, not printed.
- Drive chain: `drive_motor_mount` → **STS3215** → `servo_wheel_hub` → **4″ omni**.
- **3× omni at 120°** (LeKiwi kit layout: one aft, two forward-quarter). Do not rearrange for “symmetry” — mounts and wiring follow the kit.
- Omni tops poke above layer2; torso flange **Ø190** plus **wheel wells** over the two forward omnis so the 4″ tires can spin.
- Torso flange has **6× Ø3.4 through-holes** matching layer2’s 20 mm M3 grid (`(40,±80)`, `(±80,±40)`) — no freehand drill. `(−40,±80)` sit in the wells.
- STLs are Z-footed for the slicer (`python3 scripts/prep_print_stls.py`).
- Archived junk (wrong mounts, wrist cam, Jetson holder): `print/_archive/lekiwi/`.

Next: `HouseHand_torso.stl` → deck → **2× SO-101**. Master: `print/README.md`. Buy: `BOM_V3.md`.

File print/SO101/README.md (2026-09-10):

# SO-101 follower — print **2×**

Upstream [TheRobotStudio/SO-ARM100](https://github.com/TheRobotStudio/SO-ARM100) (Apache-2.0).

HouseHand mounts **two** followers on `HouseHand_shoulder_deck` pads (−26, ±138) mm.
Each pad has **4× Ø5** holes on the SO-ARM100 4040 pattern — bolt with **M4×30** from below and wing nuts inside the base.

## Easiest path (large bed)

Print `Follower/Prusa_Follower_SO101.stl` **twice** (one plate per arm).  
Plate is **~243×205×87 mm** — needs a **≥250 mm** bed. On ≤220 mm beds, use Individual below.

## Individual (fits ≤220 mm beds) — per arm, ×2

Follower-only parts in `Individual/` (leader parts are in `print/_archive/SO101/leader/`).  
Individual STLs are **Z-footed** for the slicer (XY kept for assembly frames).

| STL | Qty per arm |
|-----|----:|
| `Base_SO101.stl` | 1 |
| `Base_motor_holder_SO101.stl` | 1 |
| `Motor_holder_SO101_Base.stl` | 1 |
| `Under_arm_SO101.stl` | 1 |
| `Upper_arm_SO101.stl` | 1 |
| `Rotation_Pitch_SO101.stl` | 1 |
| `Wrist_Roll_Follower_SO101.stl` | 1 |
| `Wrist_Roll_Pitch_SO101.stl` | 1 |
| `Motor_holder_SO101_Wrist.stl` | 1 |
| `Moving_Jaw_SO101.stl` | 1 |
| `WaveShare_Mounting_Plate_SO101.stl` **or** `Seeedstudio_Mounting_Plate_SO101.stl` | 1 |

| Optional | Qty |
|---|----:|
| `Wrist_camera_mount_SO101.stl` | 0–1 per arm |

**Do not print** (archived leader): `Trigger_SO101`, `Handle_SO101`, `Wrist_Roll_SO101`.

## Buy

**12× STS3215** + 2× Waveshare bus. Filament ~300–400 g PLA per follower.

Master: `print/README.md` · Hardware BOM: `BOM_V3.md`

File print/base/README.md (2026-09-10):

# print/base — archived

Legacy perceptron chassis STLs have moved to `print/_archive/base/`.  
HouseHand v3 uses **LeKiwi** (`print/lekiwi/`) as the drive base.

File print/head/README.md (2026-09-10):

# print/head — alternate cam stack

SO-ARM overhead cam mounts (optional).  
**Primary** cam path (matches twin):  
`print/xlerobot/hardware/HouseHand_head_mount.stl` + `HouseHand_head_camera.stl`.

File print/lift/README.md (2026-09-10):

# print/lift — mostly archived

Prusa Z / exposed-rail STLs are in `print/_archive/lift/`.  
v3 lift is the **HouseHand torso column** (no external carriage).

Optional leftover: `4040_base_mount.stl` (only if you add 4040 bars — not in the twin).

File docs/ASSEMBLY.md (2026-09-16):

# HouseHand assembly — printable twin stack

Twin: `/model` + `/sim`. Print list: `print/README.md`. Buy list: `BOM_V3.md`.  
Generate structure: `python3 scripts/gen_structure_kit.py`.

**Product:** LeKiwi **3-omni** base + **HouseHand Ø180 torso (flange Ø190)** + shoulder deck + **2× SO-101** + neck + head cam.  
**Not** official Pollen / XLeRobot / LeKiwi. Draft — not for sale. **No RÅSKOG cart. No 4-mecanum deck.**

---

## CAD mates (locked)

1. **LeKiwi layer1** = motor deck (3× drive mount v11 + hubs + bought STS3215 + 3× 4″ omni).
2. **6× M3 hex standoffs** (`94868A713` class) space **layer1 → layer2**.
3. **HouseHand torso** Ø180 / flange Ø190 bolts to **layer2** through **6× M3** at `(40,±80)` / `(±80,±40)` (layer2 20 mm grid). **Seat the two wheel wells over the forward omnis** so the 4″ tires can spin (camera faces drive-forward). `(−40, ±80)` sit in those wells — no bolts there. Twin uses the same STL — **no fake XY scale**.
4. **Shoulder deck** registration ring slips over torso top rim; **6× M3** at r=88 (30°/90°/…). Pads at **(−26, ±138) mm** with **4× Ø5 (M4/M5)** through-holes each on the SO-ARM100 **4040 48×46.5 mm** pattern. **Ø36 cable hole** through the plate into the hollow torso.
5. **SO-101 L/R** on those pads, yawed forward with the head. M4×30 from below through pad into the base openings; wing nuts inside the base (same hardware as the official 4040 adapter — you do **not** need 4040 extrusion).
6. **Neck** on deck boss, **4× M3** at r=28; **visor head** on neck with the **same printed bolt circle**. Bought 32×32 UVC in the visor with the clamp plate (**4× M2**).
7. **12 V pack** centered in base bay; hardware e-stop cuts drive + arms.

---

## Bolt-up order

| # | Module | Mate | Fasteners |
|---|---|---|---|
| **1** | `base_plate_layer1` + 3× `drive_motor_mount` + 3× STS3215 + 3× `servo_wheel_hub` + 3× omni | Wheels @ 120° | Motor screws |
| **2** | Battery / Pi / controller mounts | On layer1 per LeKiwi | Straps / M3 |
| **3** | **6× hex standoffs** | Layer1 top → layer2 bottom | M3 into standoffs |
| **4** | `base_plate_layer2` | On standoffs | M3 |
| **5** | HouseHand torso (full **or** `_bottom`+`_top`: pins + **6× M3** through split ring) | Flange → **layer2** center, **wells over forward omnis**, plumb | **6× M3** flange; **6× M3×16** if split |
| **6** | Shoulder deck (full **or** `_L`+`_R` + `HouseHand_deck_splice`) | Ring → torso rim; pads forward | **6× M3** rim; **8× M3** splice |
| **7** | SO-101 L + R | Base on pad centers | **4× M4×30** per arm through pad (Ø5) + wing nuts inside base |
| **8** | Neck | Collar → deck boss | **4× M3** |
| **9** | Visor head + UVC | Flange → neck (printed holes); cam in visor | **4× M3** head; **4× M2** + clamp plate |
| **10** | Wire + e-stop | Pack centered | XT60 / panel |

**Exploded:** layer1 + drives → power mounts → **standoffs** → layer2 → torso → deck → arms → neck → head → wire.

---

## Torque checklist (power OFF)

1. [ ] 12 V pack centered — **REQUIRED**
2. [ ] 3× omni (no casters); each servo bridges mount → hub
3. [ ] **6× standoffs** snug between plates
4. [ ] Torso plumb on layer2; **wells over the two forward omnis**; **6× flange M3**; split ring **6× M3** if halved; wheels spin free of the flange/tube
5. [ ] Deck ring seated; **6× rim M3**; splice bar if L/R; Ø36 cable hole clear
6. [ ] Both SO-101 bases on pads, **4× M4×30** each through the 4040-pattern holes, facing forward
7. [ ] Torque **one** arm fully before the other
8. [ ] Neck **4× M3** on boss; visor head **4× M3** on printed r=28; UVC in visor with clamp plate
9. [ ] Hardware e-stop cuts drive + arms
10. [ ] L/R bus labels → bring-up

**Kill-switch:** hardware e-stop; sim **Space** = e-stop / reset.

## Drive-module note (LeKiwi cantilever)

Stock LeKiwi `drive_motor_mount-v11` hangs each STS3215 on a single-sided shaft. Dual SO-101 + head is more load than the original LeKiwi arm. Print PETG, torque the three mounts evenly, and expect some wheel wobble at speed. Bearing-supported modules (the Maker Mods approach) are a drop-in upgrade later — not in this kit.

## Sim AI

`/sim` → Train panel: teleop → Train BC → Test AI. See `docs/TRAIN.md`.

## Controls

W/S drive · A/D strafe · ←/→ turn · Q/E arms · F pick · G demo · TAB mode · Space e-stop.

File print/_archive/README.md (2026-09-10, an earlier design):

# Print archive / optional

**Do not print these for the default HouseHand robot.** Active kit: `print/README.md`.

| Path | Why archived |
|---|---|
| `lekiwi/` | Wrong motor mounts (`_v2`, B/C), LeKiwi-arm wrist cam, Jetson holder |
| `SO101/leader/` | Leader-only SO-101 parts (`Trigger`, `Handle`, `Wrist_Roll`) — not for followers |
| `optional/head_soarm_overhead/` | Alternate SO-ARM overhead cam stack (not the twin head) |
| `optional/lift_4040/` | Optional 4040 bar mounts (not in twin) |
| `optional/base_stub/` | Empty legacy base stub docs |
| `xlerobot/` | Old XLe 035 decks / RÅSKOG armbase / lattice neck |

If you intentionally want a leader arm, overhead cam, or 4040 lift, pull from here — not from the master checklist.

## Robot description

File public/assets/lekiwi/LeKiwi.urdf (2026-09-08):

<?xml version='1.0' encoding='utf-8'?>
<robot name="LeKiwi">
    <link name="base_plate_layer1-v5">
        <inertial>
            <origin xyz="-4.730687660675253e-15 -2.7155537377808555e-05 -0.0035000000000000005" rpy="0.0 0.0 0.0" />
            <mass value="1.9468624348344596" />
            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
        </inertial>
        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
    </link>
    <link name="drive_motor_mount-v11-2">
        <inertial>
            <origin xyz="-0.0005387977877578853 0.00013596517365616734 -0.0031122813365712966" rpy="0.0 -0.0 0.0" />
            <mass value="0.047242276734470956" />
            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
        </inertial>
        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
    </link>
    <link name="ST3215_Servo_Motor-v1-2">
        <inertial>
            <origin xyz="0.010251219185305343 -0.016877183343657672 -0.021914257028179583" rpy="0.0 -0.0 0.0" />
            <mass value="0.0658962961901927" />
            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
        </inertial>
        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
    </link>
    <link name="4-Omni-Directional-Wheel_Single_Body-v1-2">
        <inertial>
            <origin xyz="-9.805110055688405e-08 0.015875012090586064 -9.143534264177689e-08" rpy="0.0 -0.0 0.0" />
            <mass value="1.3542854082324305" />
            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
        </inertial>
        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
    </link>
    <link name="omni_wheel_mount-v5-2">
        <inertial>
            <origin xyz="5.9743256737576635e-09 -5.0148034724806225e-09 -0.005522899140934374" rpy="0.0 -0.0 0.0" />
            <mass value="0.1235708646349694" />
            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
        </inertial>
        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
    </link>
    <link name="drive_motor_mount-v11-1">
        <inertial>
            <origin xyz="0.00038715049105024767 -0.0003986280605619008 0.0031122813365712966" rpy="0.0 -0.0 0.0" />
            <mass value="0.047242276734470956" />
            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
        </inertial>
        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
    </link>
    <link name="ST3215_Servo_Motor-v1-1">
        <inertial>
            <origin xyz="0.01025121918530536 0.027816898485662264 -0.00435175717107704" rpy="0.0 -0.0 0.0" />
            <mass value="0.0658962961901927" />
            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
        </inertial>
        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
    </link>
    <link name="omni_wheel_mount-v5-1">
        <inertial>
            <origin xyz="0.004782968825905343 5.966875074037148e-09 0.0027614494161754166" rpy="0.0 -0.0 0.0" />
            <mass value="0.1235708646349694" />
            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
        </inertial>
        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
    </link>
    <link name="4-Omni-Directional-Wheel_Single_Body-v1-1">
        <inertial>
            <origin xyz="0.01374810955311503 -0.007937600014431929 -7.105207897817323e-08" rpy="0.0 -0.0 0.0" />
            <mass value="1.3542854082324305" />
            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
        </inertial>
        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
    </link>
    <link name="drive_motor_mount-v11">
        <inertial>
            <origin xyz="0.00015164729670767764 -0.0005345932342180682 -0.003112281336571299" rpy="0.0 -0.0 0.0" />
            <mass value="0.047242276734470956" />
            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
        </inertial>
        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
    </link>
    <link name="ST3215_Servo_Motor-v1">
        <inertial>
            <origin xyz="0.010251219185305386 -0.010539715142004517 0.02557319387622896" rpy="-6.077163357286271e-64 -0.0 0.0" />
            <mass value="0.0658962961901927" />
            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
        </inertial>
        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
    </link>
    <link name="omni_wheel_mount-v5">
        <inertial>
            <origin xyz="-0.00478297352513172 5.966875045171349e-09 0.002761449724759064" rpy="0.0 -0.0 0.0" />
            <mass value="0.1235708646349694" />
            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
        </inertial>
        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
    </link>
    <link name="4-Omni-Directional-Wheel_Single_Body-v1">
        <inertial>
            <origin xyz="-0.013748211804798878 -0.007937431357202592 -9.805855119449092e-08" rpy="0.0 1.0947644252537633e-47 6.865185903486632e-63" />
            <mass value="1.3542854082324305" />
            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
        </inertial>
        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
    </link>
    <link name="servo_controller_mount-v3">
        <inertial>
            <origin xyz="-2.072913100236695e-30 -3.385736135896877e-14 0.0031621761491414137" rpy="0.0 -0.0 0.0" />
            <mass value="0.12559881449596652" />
            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
        </inertial>
        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
    </link>
    <link name="lipo_battery_mount-v3">
        <inertial>
            <origin xyz="-0.008318729060206734 -4.4408920985006264e-17 -0.0046380028574369405" rpy="0.0 -0.0 0.0" />
            <mass value="0.2984320446179905" />
            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
        </inertial>
        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
    </link>
    <link name="Battery---Battery-5.2-Ah-DC5521-Plug-v2">
        <inertial>
            <origin xyz="-7.797576827959673e-05 -8.300646300726023e-05 0.020000000000000004" rpy="0.0 -0.0 0.0" />
            <mass value="1.2215469988184764" />
            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
        </inertial>
        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
    </link>
    <link name="94868A713_NO-THREADS_Female-Threaded-Hex-Standoff">
        <inertial>
            <origin xyz="2.1864399078485972e-14 1.2010287410706806e-09 -0.02499999330297986" rpy="0.0 -0.0 0.0" />
            <mass value="0.006150070863406618" />
            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
        </inertial>
        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
    </link>
    <link name="base_plate_layer2-v3">
        <inertial>
            <origin xyz="1.4406667835883843e-14 -0.000737848116891558 0.0034999999999999966" rpy="0.0 -0.0 0.0" />
            <mass value="1.9153836917607525" />
            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
        </inertial>
        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
    </link>
    <link name="Bottom-V2-v3">
        <inertial>
            <origin xyz="0.021623799145011228 0.034248555702746215 0.002860022373659428" rpy="0.0 -0.0 0.0" />
            <mass value="0.14588862570926195" />
            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
        </inertial>
        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
    </link>
    <link name="Top-V2-v2">
        <inertial>
            <origin xyz="0.00394392416615524 -0.00045096335632409 0.021552698750372336" rpy="0.0 -0.0 0.0" />
            <mass value="0.1256590419653392" />
            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
        </inertial>
        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
    </link>
    <link name="Camera-Mount-v8">
        <inertial>
            <origin xyz="-0.019889007343132665 0.003162253231103023 0.020248493842242046" rpy="0.0 -0.0 0.0" />
            <mass value="0.09265469509875414" />
            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
        </inertial>
        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
    </link>
    <link name="Camera-Model-v3">
        <inertial>
            <origin xyz="-0.01552129548236823 0.006733132771749837 -0.011599583774026805" rpy="0.0 2.7755575615628914e-17 0.0" />
            <mass value="0.039920058315088616" />
            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
        </inertial>
        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
    </link>
    <link name="Base_08q-v1">
        <inertial>
            <origin xyz="-0.03999704723368316 -0.03974905501648025 0.021865523723532104" rpy="0.0 -0.0 0.0" />
            <mass value="1.2829039880853146" />
            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
        </inertial>
        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
    </link>
    <link name="WaveShare_Mounting_Plate_01d-v1">
        <inertial>
            <origin xyz="-0.0036802122213187593 -0.0036094977362838856 6.824776544718247e-06" rpy="0.0 -0.0 0.0" />
            <mass value="0.07141322001638221" />
            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
        </inertial>
        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
    </link>
    <link name="Rotation_Pitch_08i-v1">
        <inertial>
            <origin xyz="0.00027157225787806426 -0.03155586567874573 0.009540449649933115" rpy="4.3790577010150533e-47 4.379057701015054e-47 -1.5557538194652858e-61" />
            <mass value="0.5385469320676795" />
            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
        </inertial>
        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
    </link>
    <link name="STS3215_03a-v1">
        <inertial>
            <origin xyz="-0.010249997314858655 0.016027064924721765 -0.019999026815617257" rpy="0.0 -0.0 0.0" />
            <mass value="0.2843033831904074" />
            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
        </inertial>
        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
    </link>
    <link name="SO_ARM100_08k_Asym_Mirror_Clip-v1">
        <inertial>
            <origin xyz="-0.023249790543467236 0.009494231975835899 0.002658209837920218" rpy="0.0 -0.0 0.0" />
            <mass value="0.10853073755546007" />
            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
        </inertial>
        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
    </link>
    <link name="Passive_Horn_01-v1">
        <inertial>
            <origin xyz="2.6917174546039143e-09 -0.0010740097666846627 -7.475931163014593e-10" rpy="0.0 -0.0 0.0" />
            <mass value="0.00454511487954422" />
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

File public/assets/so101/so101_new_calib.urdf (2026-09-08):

<?xml version="1.0" encoding="utf-8"?>
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
<robot name="so101_new_calib">

  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
  <link name="base_link">
    <inertial>
      <origin xyz="0.0137179 -5.19711e-05 0.0334843" rpy="0 0 0"/>
      <mass value="0.147"/>
      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
    </inertial>
    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
  </link>

  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
  <link name="shoulder_link">
    <inertial>
      <origin xyz="-0.0307604 -1.66727e-05 -0.0252713" rpy="0 0 0"/>
      <mass value="0.100006"/>
      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
    </inertial>
    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
  </link>

  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
  <link name="upper_arm_link">
    <inertial>
      <origin xyz="-0.0898471 -0.00838224 0.0184089" rpy="0 0 0"/>
      <mass value="0.103"/>
      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
    </inertial>
    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
  </link>

  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
  <link name="lower_arm_link">
    <inertial>
      <origin xyz="-0.0980701 0.00324376 0.0182831" rpy="0 0 0"/>
      <mass value="0.104"/>
      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
    </inertial>
    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
  </link>

  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
  <link name="wrist_link">
    <inertial>
      <origin xyz="-0.000103312 -0.0386143 0.0281156" rpy="0 0 0"/>
      <mass value="0.079"/>
      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
    </inertial>
    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
  </link>

  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
  <link name="gripper_link">
    <inertial>
      <origin xyz="0.000213627 0.000245138 -0.025187" rpy="0 0 0"/>
      <mass value="0.087"/>
      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
    </inertial>
    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
  </link>

  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
  <link name="gripper_frame_link">
    <origin xyz="0 0 0" rpy="0 -0 0"/>
    <inertial>
      <origin xyz="0 0 0" rpy="0 0 0"/>
      <mass value="1e-9"/>
      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
    </inertial>
  </link>

  <joint name="gripper_frame_joint" type="fixed">
    <origin xyz="-0.0079 -0.000218121 -0.0981274" rpy="0 3.14159 0"/>
    <parent link="gripper_link"/>
    <child link="gripper_frame_link"/>
    <axis xyz="0 0 0"/>
  </joint>

  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
  <link name="moving_jaw_so101_v1_link">
    <inertial>
      <origin xyz="-0.00157495 -0.0300244 0.0192755" rpy="0 0 0"/>
      <mass value="0.012"/>
      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
    </inertial>
    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
  </link>

  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
  <joint name="gripper" type="revolute">
    <origin xyz="0.0202 0.0188 -0.0234" rpy="1.5708 -5.24284e-08 -1.41553e-15"/>
    <parent link="gripper_link"/>
    <child link="moving_jaw_so101_v1_link"/>
    <axis xyz="0 0 1"/>
    <limit effort="10" velocity="10" lower="-0.174533" upper="1.74533"/>
  </joint>

  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
  <joint name="wrist_roll" type="revolute">
    <origin xyz="5.55112e-17 -0.0611 0.0181" rpy="1.5708 0.0486795 3.14159"/>
    <parent link="wrist_link"/>
    <child link="gripper_link"/>
    <axis xyz="0 0 1"/>
    <limit effort="10" velocity="10" lower="-2.74385" upper="2.84121"/>
  </joint>

  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
  <joint name="wrist_flex" type="revolute">
    <origin xyz="-0.1349 0.0052 3.62355e-17" rpy="4.02456e-15 8.67362e-16 -1.5708"/>
    <parent link="lower_arm_link"/>
    <child link="wrist_link"/>
    <axis xyz="0 0 1"/>
    <limit effort="10" velocity="10" lower="-1.65806" upper="1.65806"/>
  </joint>

  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
  <joint name="elbow_flex" type="revolute">
    <origin xyz="-0.11257 -0.028 1.73763e-16" rpy="-3.63608e-16 8.74301e-16 1.5708"/>
    <parent link="upper_arm_link"/>
    <child link="lower_arm_link"/>
    <axis xyz="0 0 1"/>
    <limit effort="10" velocity="10" lower="-1.69" upper="1.69"/>
  </joint>

  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
  <joint name="shoulder_lift" type="revolute">
    <origin xyz="-0.0303992 -0.0182778 -0.0542" rpy="-1.5708 -1.5708 0"/>
    <parent link="shoulder_link"/>
    <child link="upper_arm_link"/>
    <axis xyz="0 0 1"/>
    <limit effort="10" velocity="10" lower="-1.74533" upper="1.74533"/>
  </joint>

  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
  <joint name="shoulder_pan" type="revolute">
    <origin xyz="0.0388353 -8.97657e-09 0.0624" rpy="3.14159 4.18253e-17 -3.14159"/>
    <parent link="base_link"/>
    <child link="shoulder_link"/>
    <axis xyz="0 0 1"/>
    <limit effort="10" velocity="10" lower="-1.91986" upper="1.91986"/>
  </joint>

  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 

</robot>

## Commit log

2026-09-07 Initial Pebble product site + browser sim
    Microduck body + SO-101 arm meshes, Vite/React playground, BOM/docs.
    Configured for GitHub Pages under /pebble/.
    [pebble.scad, so101_new_calib.urdf]
2026-09-07 First-principles cleanup: lean product site, drop unused fluff
    Remove dead components, PRICE_PACKS, and marketing chrome. Keep
    what Pebble is, sim, BOM/specs, and short docs — mesh imports and
    GitHub Pages base intact.
2026-09-07 CAD twin: fix Microduck facing + SO-101 side mounts, tank controls, train hooks
    Microduck STL is +X-forward; sim treated +Z as forward so beak and arms
    were 90° off (arms on chest/back). Orient body Rx(-90°)+Ry(-90°); mount
    both SO-101s on ±X flanks reaching +Z without mirrored scale. Unicycle
    uses pre-step heading; expose src/sim/train.ts + window.__PEBBLE_TRAIN__.
2026-09-07 Fix inverted left/right yaw and arm flanks
    A/D (and touch) were mirrored vs visual yaw; left arm was on +X (right flank).
2026-09-07 Reposition Pebble as wheeled home chore bot + one SO-101
    Drop Microduck-as-product framing for a low differential-drive base,
    mast camera, and default single SO-101 arm. Rewrite site/BOM around
    cost-first DIY twin; sim shows procedural placeholder chassis + SO-101
    GLB with table/box props and E pick/drop.
2026-09-07 Printable twin: base STLs + SO-101 library; sim loads real parts
    Replace procedural chassis with authored print/base STLs (also public/assets/base),
    vendor SO-101 follower printables under print/SO101, keep follower_idle.glb as
    URDF-baked printable arm mesh. Docs/BOM/ASSEMBLY list print files; tires bought.
    [Base_SO101.stl, Base_motor_holder_SO101.stl, Handle_SO101.stl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]
2026-09-07 Humanoid twin: dual SO-101 hang + torso/head, floor-to-counter reach
    Wider wheeled base, printable torso/shoulder/head STLs, 2x SO-101 default
    with idle hang remount; BOM/docs honesty on tip risk and dual-arm cost.
    [camera_mount.stl, camera_shelf.stl, caster_mount.stl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]
2026-09-07 Compose Pebble from real OSS meshes (no generated bodies)
    Replace numpy-stl placeholders with perceptron_bot base (MIT),
    Prusa Z/x-end lead-screw carriage (GPL-2.0), SO-ARM cam/4040
    (Apache-2.0), dual SO-101. Overall 1730 mm via bought extrusion;
    Q/E lift; full BOM + NOTICE; Pages /pebble/.
    [4040_base_mount.stl, back_lower_wall.stl, back_upper_wall.stl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]
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2026-09-07 Add /model orbit viewer, cheap ~$740 dual BOM, IRL twin fixes
    Shared RobotAssembly for sim+model; caster mmToM; 1:1 head; coax screw
    axis; seated SO-101 on 4040; drop pose.bob; quarantine Microduck; dual
    SO-101 print README. BOM cuts Pi 4GB, DIY arms ~$125, no MGN12.
2026-09-07 Poka-yoke: soft lift limits, tip slowdown, keyed L/R, docs checklist
    Sim HUD shows LIMIT + tip slow %; Space e-stop hint; Model bought-vs-printed
    captions; ASSEMBLY/Docs power-off-first, ballast, can't-wire-wrong, blue/orange mounts.
2026-09-07 Chore stack ~1200 mm: laundry+dishes reach, dual BOM ~$655
    Shorten extrusion/lift for counters/washer rim/floor; keep dual SO-101;
    cut Pi/cam/column; soft pads + wipe; sim kitchen+laundry props; docs limits.
2026-09-07 Critic P0–P2: tip physics, MGN12, chore demos, safety BOM
    Outriggers 400 mm + 4 kg ballast → tip≈7.85 / restore≈9.6 / margin≈1.22×;
    live tip HUD + tipOver freeze (slowdown UX-only). MGN12H REQUIRED on twin+BOM.
    G cycles floor→basket, wipe contact, washer@900; held Y tracks AGL. Dual BOM ~$715.
    [pebble.scad]
2026-09-07 Fix IRL twin head centering + SO-101 flush on 4040 mounts
    Head: 1:1 cam boom centered on column (stl_center_x), face/UVC at boom tip.
    Arms: world-anchored 4040 faces at ±mount_x from STL bbox math; base_link
    flush; nested yaw+tip so both hang outboard (R was inverted). No P0 regress.
2026-09-07 Attach arms via yoke bridge; nest head on column
    Continuous carriage→4040→base_link path plus outrigger beams so mounts
    no longer float; compact on-column face (no forward boom poke).
2026-09-07 Re-parent 4040+SO-101 under carriage lift group
    4040 mounts and arms are children of [screwX, carriageY] so the twin
    shows a continuous load path; head at X=0 on column (no stl_center poke).
2026-09-07 Parent MGN carriage block under lift group
    Optional continuous-path polish: MGN block local ≈ [-18,0,14] mm
    instead of world-sibling AGL sync.
2026-09-07 Replace SO-101 GLB with link-envelope arms; 8-module assemble docs
    Drop useGLTF/follower_idle from the live twin (FPS hang) in favor of
    SimpleSO101Arm boxes from SO101+STS3215 dims; add yoke crossbar mate.
    ASSEMBLY.md is an 8-module bolt-up tree with tip/MGN/T8/ballast locks.
    BOM/Model captions still price bought SO-101 kits + STS3215×12 (~$715).
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2026-09-08 Load real LeKiwi + SO-101 URDF CAD in the twin.
    Replace generated envelopes with printable Onshape meshes so /model and /sim match the parts you can actually build.
    [4-Omni-Directional-Wheel_Single_Body-v1-1.stl, 4-Omni-Directional-Wheel_Single_Body-v1-2.stl, 4-Omni-Directional-Wheel_Single_Body-v1.stl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]
2026-09-08 Assemble the twin as LeKiwi + printable torso + XLe shoulders and neck.
    The cart is out of the kit; the model now stacks a printable 120×320 mm shell on the kiwi plate under real XLeRobot arm-base, neck, and dual SO-101 CAD.
    [Base.stl, Base_Motor.stl, Fixed_Jaw.stl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]
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2026-09-08 Mount dual SO-101 URDFs on the XLe shoulder pack.
    Replace the floating full-XLe cart URDF arms with two so101_new_calib instances seated on the printable armbase so the twin shows attached L/R chore arms.
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2026-09-09 Show the full XLeRobot twin: cart base, dual arms, OG head.
    Drop the LeKiwi + STL collage stack. Load xlerobot.urdf so the RÅSKOG base, both SO-101 trees on the cart platform, and the original pan/tilt head stay correctly parented with all meshes visible.
2026-09-09 Drop the IKEA RÅSKOG cart from the twin; keep wheels, arms, and head.
    Skip the heavy cart STL, seat mounts on the wheeled deck, and harden URDF
    loading so the model appears sooner (especially on mobile).
2026-09-09 Swap RÅSKOG 4-wheels for LeKiwi 3-wheel omni base (no arm).
    Keep XLe dual arms and OG head; skip cart wheels/body; seat the upper
    stack on the LeKiwi plate.
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2026-09-09 Fix Sim twin seating and clear the arena props.
    Seat the robot in local space so Sim motion no longer scatters parts,
    and remove kitchen/chore props and the ball from the sim environment.
2026-09-09 Fix Sim seating under parent pose; spawn teleop at origin.
    Zero ancestor transforms while seating so yaw/offset no longer warps
    AABBs and scatter the twin. Start sim in teleop at the origin.
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2026-09-09 Speed up mobile twin load and draw.
    Replace 15MB omni-wheel STLs with cylinder proxies, skip heavy base
    detail on phones, and lower DPR/shadows/antialias on mobile.
2026-09-09 Restore real LeKiwi omni-wheel STLs.
    Remove the broken cylinder proxies so the three CAD wheels load and
    seat correctly again.
2026-09-09 Reveal the twin only after all meshes finish loading.
    Stop mounting URDFs mid-download so mobile browsers no longer pop in
    body parts one STL at a time; show a placeholder until the full robot
    is seated.
2026-09-09 Recolor entire twin body from the colourway picker
    Apply colour.primary to all visible LeKiwi and XLe meshes instead of
    keeping wheels, servos, and left/right arms on fixed accent palettes.
2026-09-09 Restore printable XLe armbase and neck on the twin stack
    The detailed shoulder pack and hollow neck STLs were dropped when the
    scene switched to URDF-only upper. Stack torso → 0.35 armbase → neck
    again, seat arms/head on the neck, and skip URDF topbase stand-ins.
2026-09-09 Seat arms on the armbase and head on the neck
    Stop parking the whole URDF upper on the neck top (which left the head
    floating). Place SO-101 Base flanges on the printable armbase, then
    nudge fixed_top_base_link so the OG head kisses the neck.
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2026-09-09 Fix SO-101 body tint and harden URDF mesh readiness
    Re-tint arms after seating (URDF default is yellow), duck-type meshes for
    colorize, and defer the idle mesh check so arms are not exposed unpainted.
2026-09-09 Wait for SO-101 meshes before exposing the twin
    Do not finish URDF load until pending meshes have arrived, so the initial
    colourway tint replaces the yellow 3d_printed materials on first paint.
2026-09-09 Fix cam head, arm flanges, facing, and mount gap
    Replace the D435 print-plate STL with the XLe OG camera head, seat both
    SO-101 circular flanges flush on the armbase, and give L/R the same
    forward pose (R still π-mirrored).
2026-09-09 Point both arms forward and pin flange seats in state
    Drop the right-arm π flip that aimed one arm backward, keep mirrored
    outward pan, double-pass flange seating, and persist arm poses in React
    state so the circular bases stay flush on the armbase.
2026-09-09 Use RealSense cam head and fix arm mounts
    Swap the gimbal print-plate for tophead + XLeRobot camera STLs, keep
    printables in one mm stack so torso meets armbase, clone SO-101 meshes
    so both circular flanges show, and seat both arms facing forward flush
    on the platform.
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2026-09-09 Yaw right SO-101 180° so both arms face forward
    Replace the X-scale mirror (which pointed one arm backward and hid one
    circular flange under the armbase) with the XLeRobot fixed_Base_2 π yaw
    so both flanges match and both arms face forward.
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2026-09-09 Seat SO-101s on a symmetric armbase top deck
    The stock 035 armbase had a mid shelf on only one side and a top deck
    only ±60 mm wide, while mounts sat at ±110 mm — one circular flange looked
    missing. Mirror that shelf, move mounts to ±50 mm on the top deck, and keep
    the right-arm π yaw on an inner group so seating cannot clear it.
    [XLeRobot_035_armbase_symmetric.stl]
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2026-09-09 Place matched mount pads on the deck under both arms
    Draw the circular plates as fixed deck discs (not arm children) and seat
    both SO-101s on top of them with the same forced joint pose so both sides
    show a plate and face the same way.
2026-09-09 Use ring mount pads so both arm plates stay visible
    Replace solid discs (hidden under motor housings on one side) with wide
    annuli around each SO-101 base so both sides show a circular plate.
2026-09-09 Seat arms forward on side pads and drop the neck flush
    Yaw both SO-101s π so the shared pose faces rover-forward, mount them on
    the ±110 mm side pads (not the center deck), use a deck STL that keeps
    those pads, and close any float gap so the neck sits on the armbase.
    [XLeRobot_035_armbase_deck.stl]
2026-09-09 Mount arms on outer side pads and flatten the armbase deck
    Squash the armbase to a coplanar 110 mm deck, place SO-101s at the
    circular pad centers (±150 mm) facing forward, and iteratively seat the
    neck flush on that deck.
    [XLeRobot_035_armbase_deck.stl]
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2026-09-09 Add print kit checklist and in-sim behavioral cloning train/test.
    Sync the armbase deck STLs into print/, document the full bolt-up print list, restore beacon/box targets, and wire a Train panel so teleop demos train a browser BC policy you can Test AI against.
    [XLeRobot_035_armbase_deck.stl, XLeRobot_035_armbase_symmetric.stl]
2026-09-10 Add solid printable HouseHand shoulder deck for dual SO-101 mounts.
    Replace the fragmented XLe 035 armbase deck with a manifold HouseHand_shoulder_deck (pads at −26,±138 mm + neck boss), wire it into the twin without shelf-trimming, and update the print kit docs so every part is slicer-ready.
    [HouseHand_shoulder_deck.stl, shoulder_deck.scad]
2026-09-10 Complete printable HouseHand kit with matched Ø216 geometry.
    Regenerate torso/deck/neck as one Ø216 contract, load those STLs in the twin without fake XY scale or mesh hacks, ship head/wrist printables, archive legacy fragments, and unify print/assembly docs.
    [Gimbal_mesh_all_d435.stl, HouseHand_head_camera.stl, HouseHand_head_mount.stl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]
2026-09-10 Fix wheel/base print clearances for LeKiwi + HouseHand
    Sync print mounts to URDF v11/hubs, shrink torso to Ø180 with Ø200
    flange so layer2 seating clears omni tops (≥3 mm), and document the
    verified stack clearances for printing.
    [HouseHand_shoulder_deck.stl, HouseHand_torso.stl, base_plate_layer1.stl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]
2026-09-10 Fix floating wheels and torso seating in the twin
    Keep LeKiwi drive servos and plate standoffs visible (lean mode was
    stripping them, so hubs looked detached and the torso looked like it
    floated above layer1). Seat the stack on layer2 only, shrink the flange
    to Ø190 for ≥8 mm wheel clearance, and document the bought servo/standoff
    bridge in the print kit.
    [HouseHand_torso.stl, torso_shell.scad, torso_shell.stl]
2026-09-10 Always load full LeKiwi drive chain in the twin
    Never lean-skip base meshes on /model — mount, servo, hub, wheel, and
    plate standoffs must stay visible so the print twin matches assembly.
2026-09-10 Make the print kit actually printable end-to-end
    Align BOM/UI with the LeKiwi 3-omni + HouseHand stack, list the exact
    SO-101 follower parts (×2), require the 6× plate standoffs in assembly,
    and quarantine leader/optional/wrong STLs out of the active print folders
    so a slicer dump cannot print junk.
    [4040_base_mount.stl, Handle_SO101.stl, Trigger_SO101.stl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]
2026-09-10 Fix print-origin head mount and add bed-size splits
    Recenter HouseHand_head_mount (was ~1 m off the bed), foot all
    structure STLs to Z=0, and emit torso top/bottom + deck L/R splits so
    parts fit common ≤220 mm printers. Document bed limits in print READMEs.
    [HouseHand_head_camera.stl, HouseHand_head_mount.stl, HouseHand_neck.stl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]
2026-09-10 Align flange bolts to layer2 grid and foot the full print kit
    Highest-impact print readiness: real Ø3.4 through-holes on the LeKiwi
    20 mm grid, registration pins on bed-size splits, and Z-footed LeKiwi/
    SO-101 STLs so the slicer kit drops cleanly on the bed.
    [Base_SO101.stl, Base_motor_holder_SO101.stl, HouseHand_shoulder_deck_L.stl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]
2026-09-10 Center head flange on neck and strip LeKiwi clutter from the twin
    Head mount STL/twin now seat on the neck mating flange (not bbox center),
    camera sits on-axis, and Pi/battery/bus junk is hidden so the print twin
    matches the cheap LeKiwi + HouseHand + 2× SO-101 kit. Document the kit’s
    true 120° omni layout.
    [HouseHand_head_mount.stl]
2026-09-10 Make structure STLs bolt-up ready: through-holes, split ring, cable path
    Replace dimples with real bores, punch a Ø36 cable hole through the deck,
    add a mid-height 6× M3 split ring, deck→torso rim bolts, M4 pad holes,
    neck/head bolt circle, and a deck splice bar so bed-size halves clamp
    instead of relying on glue.
    [HouseHand_deck_splice.stl, HouseHand_head_mount.stl, HouseHand_neck.stl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]
2026-09-10 Generate a bolt-on head and lock SO-101 pad holes for print
    Head mount now prints the same r=28 M3 circle as the neck flange, plus a
    forward camera bulkhead for a 32×32 UVC. Pad holes match the SO-ARM100
    4040 4×Ø5 pattern so the arms bolt down with M4×30 rather than a guessed
    56 mm PCD. Verify script checks every fastener center is empty.
    [HouseHand_head_camera.stl, HouseHand_head_mount.stl, HouseHand_shoulder_deck.stl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]
2026-09-10 Cut torso wheel wells so the two forward omnis can spin
    The 4" front wheels poke through the flange and lower tube in the
    assembled pose. Notch those sectors (print ~90–144° and ~214–271°)
    and drop the two layer2 bolts that sat in the arches.
    [HouseHand_torso.stl, HouseHand_torso_bottom.stl, torso_shell.scad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]
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2026-09-10 Replace the place gizmo with drag and mm nudge buttons
    TransformControls froze the SwiftShader viewer. Unlocked parts now
    move by dragging in the view or with ±X/Y/Z/yaw buttons, then Lock.
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2026-09-16 Replace the camera-plate head with a visor helmet
    The printed head is now a rounded skull with ears, a chin, a cap brim, and a forward visor that still takes the 32×32 UVC on the same neck bolt circle.
    [HouseHand_head_camera.stl, HouseHand_head_mount.stl]
2026-09-16 Scale the visor helmet so it reads as a real head on the deck
    Skull is now ~148 mm wide with ears and a dark visor face; /model frames the full stack so the head sits between the SO-101s instead of cropping off the top.
    [HouseHand_head_camera.stl, HouseHand_head_mount.stl]
